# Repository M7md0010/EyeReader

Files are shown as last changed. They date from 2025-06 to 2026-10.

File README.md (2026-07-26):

# EyeReader — Assistive Blink-to-Speech & Smart-Home Wearable

> A wearable eye-blink interface that translates eyelid gestures into spoken phrases and smart-home commands for individuals with paralysis or speech impairments.

**Authors:** Mohamed Sameh & Mohamed Elawady  
**License:** MIT

---

## Table of Contents

- [Project Overview](#project-overview)
- [2022 → 2026 Evolution](#2022--2026-evolution)
- [Hardware Specifications (2026 Remaster)](#hardware-specifications-2026-remaster)
- [Firmware Architecture (2026 Remaster)](#firmware-architecture-2026-remaster)
- [Repository Structure](#repository-structure)
- [Build & Production Files](#build--production-files)
- [Blink Code Reference](#blink-code-reference)
- [Getting Started](#getting-started)
- [License](#license)

---

## Project Overview

EyeReader is a wearable assistive device that decodes voluntary eye-blink patterns — measured via a Time-of-Flight proximity sensor — into a set of pre-programmed actions. In **Speaking Mode**, blink codes trigger audio playback of phrases such as *"I need to drink"* or *"Help!!"* through a DFPlayer Mini. In **Smart-Home Mode**, the same blink vocabulary toggles GPIO-controlled appliances (lights, fans, doors, AC, etc.).

The system comprises two units:

| Unit | Role |
|---|---|
| **Transmitter** | Glasses-mounted sensor module. Detects eyelid proximity, classifies blink duration via hardware interrupts, and transmits events over BLE. |
| **Receiver** | Bedside or wearable hub. Decodes blink sequences, drives audio playback, and controls smart-home relays. |

---

## 2022 → 2026 Evolution

This project was originally built in 2022 as a high-school engineering prototype and has since been remastered as a university-level Computer Engineering portfolio piece.

| Aspect | 2022 Prototype | 2026 Remaster |
|---|---|---|
| **MCU** | 2× ESP32 DevKits (breadboarded) | Nordic nRF52840 SoC on a custom 4-layer HDI PCB |
| **Sensor** | Generic IR reflectance sensor | VL53L0X Time-of-Flight sensor over a flexible printed circuit (FPC) |
| **Wireless** | ESP-NOW (Wi-Fi based, high power) | Bluetooth Low Energy 5.0 (BLE) |
| **Antenna** | External PCB trace (hand-routed) | Standard built-in onboard zig-zag trace antenna (validated RF performance) |
| **Power Management** | USB-only, no battery | MCP73831 single-cell LiPo charger with integrated thermal regulation |
| **Haptic Driver** | Direct GPIO (no protection) | BSS138 N-Channel MOSFET + 1N4148 flyback diode motor driver |
| **Form Factor** | Breadboard + jumper wires (~120 × 80 mm) | 15 × 50 mm 4-layer HDI PCB |
| **Firmware Model** | Blocking `while` loops with `delay()` calls | Event-driven FreeRTOS architecture with hardware interrupts |
| **Power Consumption** | ~80 mA continuous (Wi-Fi always on) | ~8 µA deep sleep (BLE advertising + `waitForEvent()`) |
| **Code** | Monolithic `.ino` sketches | Modular C++ with ISR-driven state machine and RTOS software timers |

> The original 2022 code and Fritzing circuit images are preserved in the [`/Archive_2022`](Archive_2022/) directory for reference.

---

## Hardware Specifications (2026 Remaster)

### PCB

- **Dimensions:** 15 × 50 mm, 4-layer HDI stack-up
- **Fabrication:** Standard JLCPCB/PCBWay-compatible Gerber output
- **Design Tool:** KiCad 8.x

### Core Components

| Component | Part Number | Function |
|---|---|---|
| **SoC** | Nordic nRF52840 | ARM Cortex-M4F @ 64 MHz, BLE 5.0, 1 MB Flash, 256 KB RAM |
| **ToF Sensor** | VL53L0X (ST) | 940 nm VCSEL laser ranging, I²C, hardware interrupt on threshold crossing. Mounted on FPC for flexible glasses-frame routing. |
| **LiPo Charger** | MCP73831 (Microchip) | Single-cell Li-Ion/LiPo charge management, 500 mA programmable charge current, thermal regulation |
| **Haptic Driver** | BSS138 + 1N4148 | Low-side N-FET switch for ERM vibration motor with flyback protection diode |

### RF Design

The RF front-end utilizes the **standard built-in onboard zig-zag trace antenna** pattern routed on the PCB top layer. This antenna geometry is a well-characterized design for 2.4 GHz BLE applications and was selected for its compact footprint and proven radiation efficiency without requiring an external antenna or matching network. The design has been validated for reliable BLE communication at the target operating range.

### Power Architecture

```
USB-C → MCP73831 → LiPo Cell (3.7V)
                 ↘ LDO → nRF52840 (1.8V–3.3V)
                       → VL53L0X (2.8V via XSHUT gating)
```

- **Deep sleep current:** ~8 µA (nRF52840 System ON, RAM retained, BLE advertising at 244 ms interval)
- **Active sensing current:** ~12 mA (ToF continuous ranging at 50 ms period)

---

## Firmware Architecture (2026 Remaster)

The firmware has been completely re-architected from the original ESP32 blocking-loop design to an **event-driven RTOS model** on the nRF52840.

### Key Design Decisions

1. **Hardware Interrupt-Driven Sensing:**  
   The VL53L0X is configured with a programmable distance threshold. When the eyelid crosses this threshold, the sensor asserts its GPIO interrupt pin. An ISR (`tof_isr`) captures the timestamp on both edges — eliminating continuous polling and enabling the MCU to remain in deep sleep between blinks.

2. **FreeRTOS Software Timers for Haptics:**  
   Haptic feedback (vibration motor pulse on long blinks ≥ 1000 ms) is managed by a one-shot FreeRTOS `SoftwareTimer` rather than a blocking `delay()`. This keeps the main loop non-blocking and power-efficient.

3. **Dynamic Threshold Detection:**  
   The blink threshold (currently 20 mm) is designed to be dynamically calibrated via a button ISR (pin reserved, TODO in firmware). This accommodates per-user anatomical variation.

4. **BLE Notification Model:**  
   Blink duration is transmitted as a 32-bit unsigned integer via a BLE GATT characteristic with `NOTIFY` property. The receiver subscribes to notifications and processes blink codes asynchronously — no polling or request/response overhead.

5. **Ultra-Low Power Loop:**  
   After processing a blink event, the main loop calls `waitForEvent()` (ARM WFE instruction), immediately returning the CPU to deep sleep. The loop thread is also suspended at startup via `suspendLoop()`, ensuring zero idle power waste.

### Firmware Files

| File | Description |
|---|---|
| [`Firmware/Transmitter.cpp`](Firmware/Transmitter.cpp) | nRF52840 transmitter — ISR-driven blink detection, BLE GATT server, FreeRTOS haptic timer |
| [`Firmware/EyeReaderReciever.ino`](Firmware/EyeReaderReciever.ino) | ESP32 BLE client receiver — blink code decoder, DFPlayer audio, smart-home GPIO control |

---

## Repository Structure

```
EyeReader/
├── Hardware/              # KiCad 8.x project files (schematic, PCB, netlist)
│   ├── v1.0.kicad_pro
│   ├── v1.0.kicad_sch
│   ├── v1.0.kicad_pcb
│   └── ...
├── Firmware/              # nRF52840 + ESP32 BLE firmware (2026)
│   ├── Transmitter.cpp
│   └── EyeReaderReciever.ino
├── Docs/                  # Generated documentation (schematic PDFs, etc.)
├── Production/            # Manufacturing output (Gerbers, drill files)
├── Archive_2022/          # Original high-school prototype code & images
│   ├── EyeReaderTransmitter_ESP32.ino
│   ├── EyeReaderReciever_ESP32.ino
│   ├── Transmitter Circuit.jpg
│   └── Receiver Circuit.jpg
├── generate_production.sh # KiCad CLI export automation script
└── README.md              # This file
```

---

## Build & Production Files

### Automated Export Script

A bash script is provided to generate all manufacturing and documentation files from the KiCad project:

```bash
./generate_production.sh
```

This script uses the KiCad CLI to:
1. **Export schematic PDF** → `Docs/EyeReader_Schematic.pdf`
2. **Export Gerber files** → `Production/`
3. **Export drill files** → `Production/`

> **Prerequisites:** KiCad 8.x must be installed and `kicad-cli` available on `$PATH`.

---

## Blink Code Reference

Each blink is classified by duration:  
- `0` = Short blink (1–2 s)  
- `1` = Long blink (2–3 s)  
- `2` = End-of-sequence marker (0.5–1 s)  
- **Mode switch** = Very long blink (3–5 s)

### Speaking Mode

| Code | Phrase |
|---|---|
| `0-0-2` | "I need to drink" |
| `0-1-2` | "I need to eat" |
| `1-0-0-2` | "I need to obey nature's call" |
| `1-1-0-2` | "Help!!" |
| `1-0-1-2` | "Hello" |
| `1-1-2` | "I am cold" |
| `1-1-1-2` | "Thanks" |
| `0-1-0-2` | "Give me a hug" |
| `0-0-1-2` | "I need to shower" |
| `0-0-0-2` | "I love you" |
| `0-1-1-2` | "Tell me a joke" |

### Smart-Home Mode

| Code | Action |
|---|---|
| `0-0-2` | Toggle lamp |
| `0-1-2` | Toggle TV |
| `1-0-0-2` | Toggle fan |
| `1-1-0-2` | Open/close curtains |
| `1-0-1-2` | Open/close door |
| `1-1-2` | Toggle AC/heater |
| `1-1-1-2` | Read a book |
| `0-1-0-2` | Medication schedule |
| `0-0-1-2` | Monitor cameras |
| `0-0-0-2` | Make a call |
| `0-1-1-2` | Measure heart rate |

---

## Getting Started

### Hardware
1. Open the KiCad project from `Hardware/v1.0.kicad_pro`.
2. Review the schematic and PCB layout.
3. Run `./generate_production.sh` to generate Gerber and drill files for PCB fabrication.

### Firmware
1. **Transmitter (nRF52840):** Open `Firmware/Transmitter.cpp` in the Arduino IDE with the Adafruit nRF52 BSP installed. Select the `Adafruit Feather nRF52840` board (or your target) and upload.
2. **Receiver (ESP32):** Open `Firmware/EyeReaderReciever.ino` in the Arduino IDE with the ESP32 board package. Upload to the receiver ESP32.

### Dependencies
- [Adafruit nRF52 Arduino BSP](https://github.com/adafruit/Adafruit_nRF52_Arduino)
- [Adafruit VL53L0X Library](https://github.com/adafruit/Adafruit_VL53L0X)
- [DFRobotDFPlayerMini Library](https://github.com/DFRobot/DFRobotDFPlayerMini)

---

## License

This project is licensed under the MIT License — see the [LICENSE](LICENSE) file for details.

---

**Mohamed Sameh** · [GitHub](https://github.com/m7md0010)  
**Mohamed Elawady** · Co-Author

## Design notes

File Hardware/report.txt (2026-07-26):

Info: Processing symbol 'C1:'.
Info: Processing symbol 'L3:'.
Info: Processing symbol 'C2:'.
Info: Processing symbol 'J2:'.
Info: Processing symbol 'C3:'.
Info: Processing symbol 'J3:'.
Info: Processing symbol 'C4:'.
Info: Processing symbol 'J4:'.
Info: Processing symbol 'C5:'.
Info: Processing symbol 'L1:'.
Info: Processing symbol 'C6:'.
Info: Processing symbol 'C12:'.
Info: Processing symbol 'C7:'.
Info: Processing symbol 'L2:'.
Info: Processing symbol 'C8:'.
Info: Processing symbol 'L4:'.
Info: Processing symbol 'C9:'.
Info: Processing symbol 'M1:'.
Info: Processing symbol 'C10:'.
Info: Processing symbol 'Q1:Package_TO_SOT_SMD:SOT-23'.
Info: Processing symbol 'C11:'.
Info: Processing symbol 'R1:'.
Info: Processing symbol 'R2:'.
Info: Processing symbol 'R3:'.
Info: Processing symbol 'C13:'.
Info: Processing symbol 'R4:'.
Info: Processing symbol 'C14:'.
Info: Processing symbol 'R5:'.
Info: Processing symbol 'C15:'.
Info: Processing symbol 'R6:'.
Info: Processing symbol 'C16:'.
Info: Processing symbol 'R7:'.
Info: Processing symbol 'C17:'.
Info: Processing symbol 'R8:'.
Info: Processing symbol 'C18:'.
Info: Processing symbol 'R9:'.
Info: Processing symbol 'C19:'.
Info: Processing symbol 'U1:Package_DFN_QFN:DFN-8-1EP_3x2mm_P0.5mm_EP1.7x1.4mm'.
Info: Processing symbol 'C20:'.
Info: Processing symbol 'U2:Package_DFN_QFN:Nordic_AQFN-73-1EP_7x7mm_P0.5mm'.
Info: Processing symbol 'D1:'.
Info: Processing symbol 'U3:LGA12_STM'.
Info: Processing symbol 'D2:Diode_THT:D_DO-35_SOD27_P7.62mm_Horizontal'.
Info: Processing symbol 'Y1:'.
Info: Processing symbol 'J1:'.
Add D2 (footprint 'Diode_THT:D_DO-35_SOD27_P7.62mm_Horizontal').
Add U2 (footprint 'Package_DFN_QFN:Nordic_AQFN-73-1EP_7x7mm_P0.5mm').
Add Q1 (footprint 'Package_TO_SOT_SMD:SOT-23').
Add U1 (footprint 'Package_DFN_QFN:DFN-8-1EP_3x2mm_P0.5mm_EP1.7x1.4mm').
Add U3 (footprint 'LGA12_STM').
Warning: Warning: U3 footprint 'LGA12_STM' is missing a library name. Use the full 'Library:Footprint' format to avoid repeated update notifications.
Error: Cannot add C7 (no footprint assigned).
Error: Cannot add C8 (no footprint assigned).
Error: Cannot add C9 (no footprint assigned).
Error: Cannot add C10 (no footprint assigned).
Error: Cannot add C11 (no footprint assigned).
Error: Cannot add C6 (no footprint assigned).
Error: Cannot add C12 (no footprint assigned).
Error: Cannot add C13 (no footprint assigned).
Error: Cannot add C14 (no footprint assigned).
Error: Cannot add C15 (no footprint assigned).
Error: Cannot add C16 (no footprint assigned).
Error: Cannot add C17 (no footprint assigned).
Error: Cannot add C18 (no footprint assigned).
Error: Cannot add C19 (no footprint assigned).
Error: Cannot add C20 (no footprint assigned).
Error: Cannot add D1 (no footprint assigned).
Error: Cannot add R2 (no footprint assigned).
Error: Cannot add J1 (no footprint assigned).
Error: Cannot add R3 (no footprint assigned).
Error: Cannot add L3 (no footprint assigned).
Error: Cannot add R4 (no footprint assigned).
Error: Cannot add J4 (no footprint assigned).
Error: Cannot add R5 (no footprint assigned).
Error: Cannot add L4 (no footprint assigned).
Error: Cannot add R6 (no footprint assigned).
Error: Cannot add J3 (no footprint assigned).
Error: Cannot add R7 (no footprint assigned).
Error: Cannot add M1 (no footprint assigned).
Error: Cannot add R8 (no footprint assigned).
Error: Cannot add C1 (no footprint assigned).
Error: Cannot add R9 (no footprint assigned).
Error: Cannot add C2 (no footprint assigned).
Error: Cannot add C3 (no footprint assigned).
Error: Cannot add J2 (no footprint assigned).
Error: Cannot add L1 (no footprint assigned).
Error: Cannot add R1 (no footprint assigned).
Error: Cannot add C4 (no footprint assigned).
Error: Cannot add C5 (no footprint assigned).
Error: Cannot add L2 (no footprint assigned).
Error: Cannot add Y1 (no footprint assigned).

Info: Total warnings: 1, errors: 40.

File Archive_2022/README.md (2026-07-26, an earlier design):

# Archive — 2022 High School Prototype

This directory contains the original EyeReader code and circuit images from the 2022 prototype.

These files are preserved for historical reference. The 2022 version used:
- 2× ESP32 DevKit boards communicating via **ESP-NOW**
- Generic IR reflectance sensor for blink detection
- Blocking `while` loops with `delay()` calls
- Breadboard construction with jumper wires

## Files

| File | Description |
|---|---|
| `EyeReaderTransmitter_ESP32.ino` | Original ESP32 transmitter sketch (IR sensor + ESP-NOW) |
| `EyeReaderReciever_ESP32.ino` | Original ESP32 receiver sketch (ESP-NOW + DFPlayer) |
| `Transmitter Circuit.jpg` | Fritzing-style wiring diagram for the transmitter |
| `Receiver Circuit.jpg` | Fritzing-style wiring diagram for the receiver |

> See the root [README.md](../README.md) for a detailed comparison with the 2026 remaster.

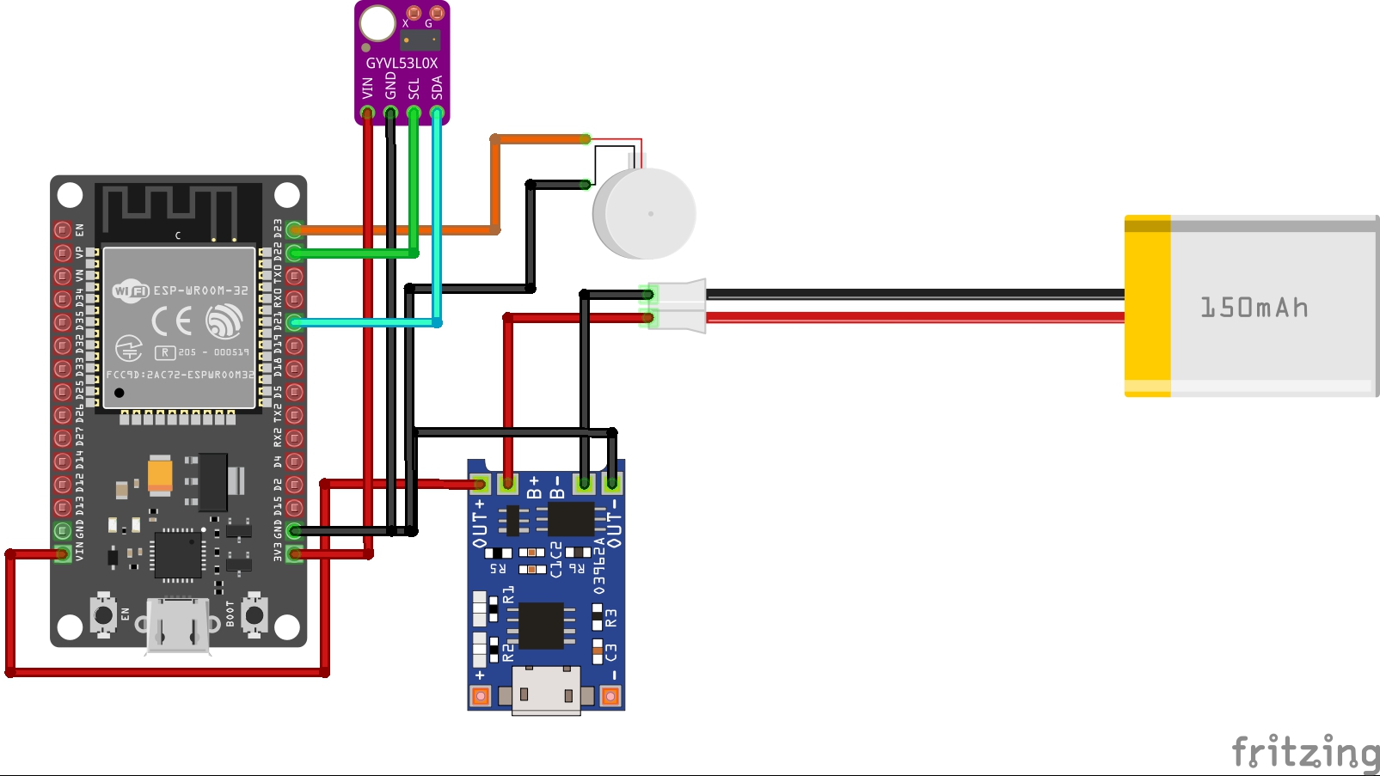
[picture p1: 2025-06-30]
Transmitter Circuit.jpg

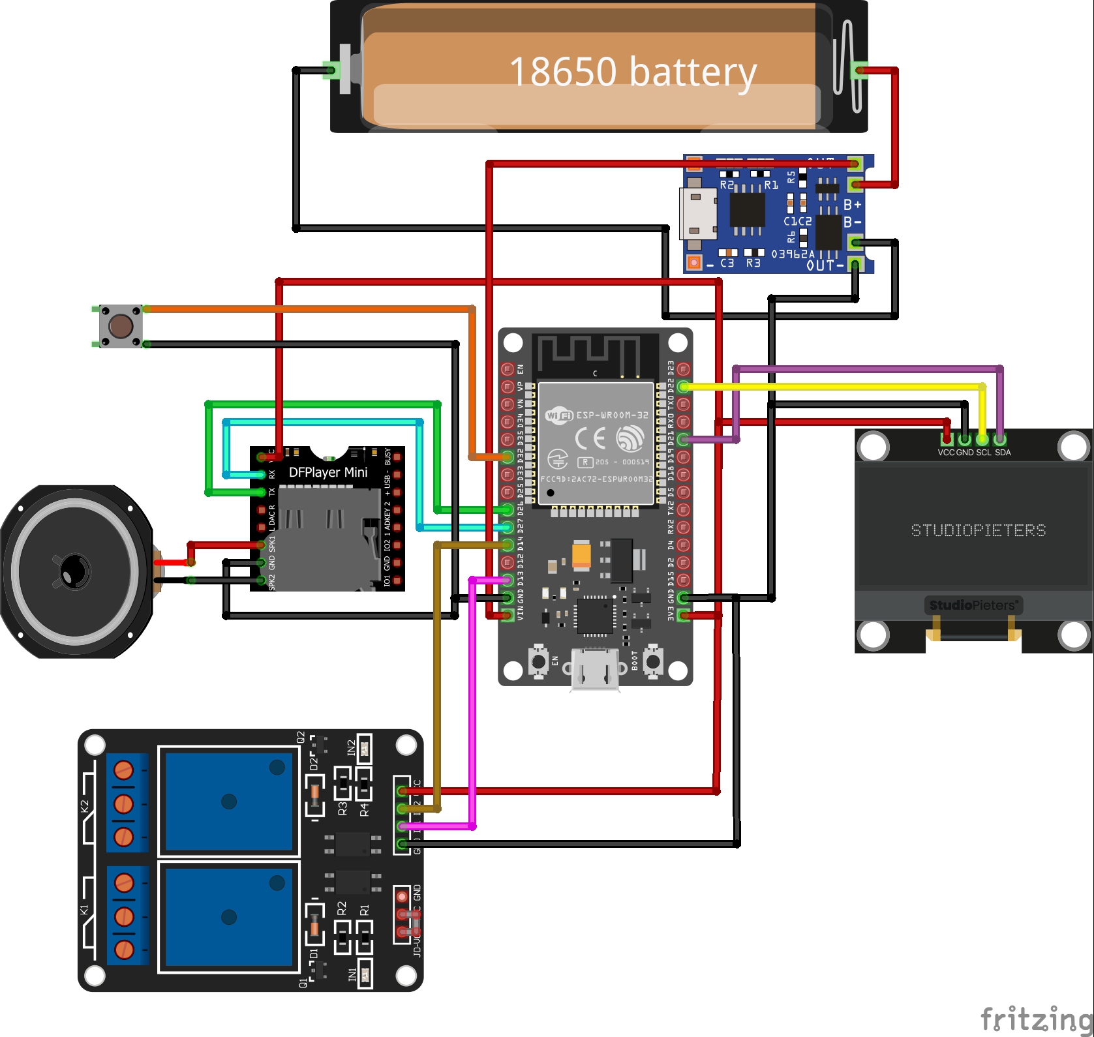
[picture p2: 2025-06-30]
Receiver Circuit.jpg

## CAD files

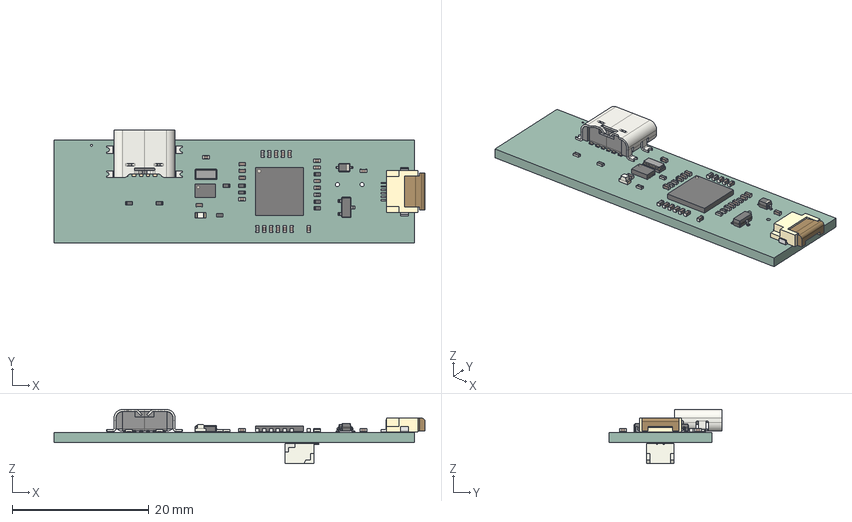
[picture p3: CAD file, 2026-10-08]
Hardware/EyeReader_3D.step
54.2 x 16.5 x 7.90 mm
C_0402_1005Metric x 20
Crystal_SMD_3215-2Pin_3.2x1.5mm
D_SOD-323
R_0402_1005Metric x 9
L_0402_1005Metric x 4
USB_C_Receptacle_6P_TopMnt_Horizontal_GCT_USB4135-GF-A
LED_0603_1608Metric
Nordic_AQFN-73-1EP_7x7mm_P0.5mm
SOT-23
lock
pins
Maxim_WSON-8-1EP_3x2mm_P0.5mm_EP1.75x1.63mm
JST_SH_SM02B-SRSS-TB_1x02-1MP_P1.00mm_Horizontal
v1.0_PCB

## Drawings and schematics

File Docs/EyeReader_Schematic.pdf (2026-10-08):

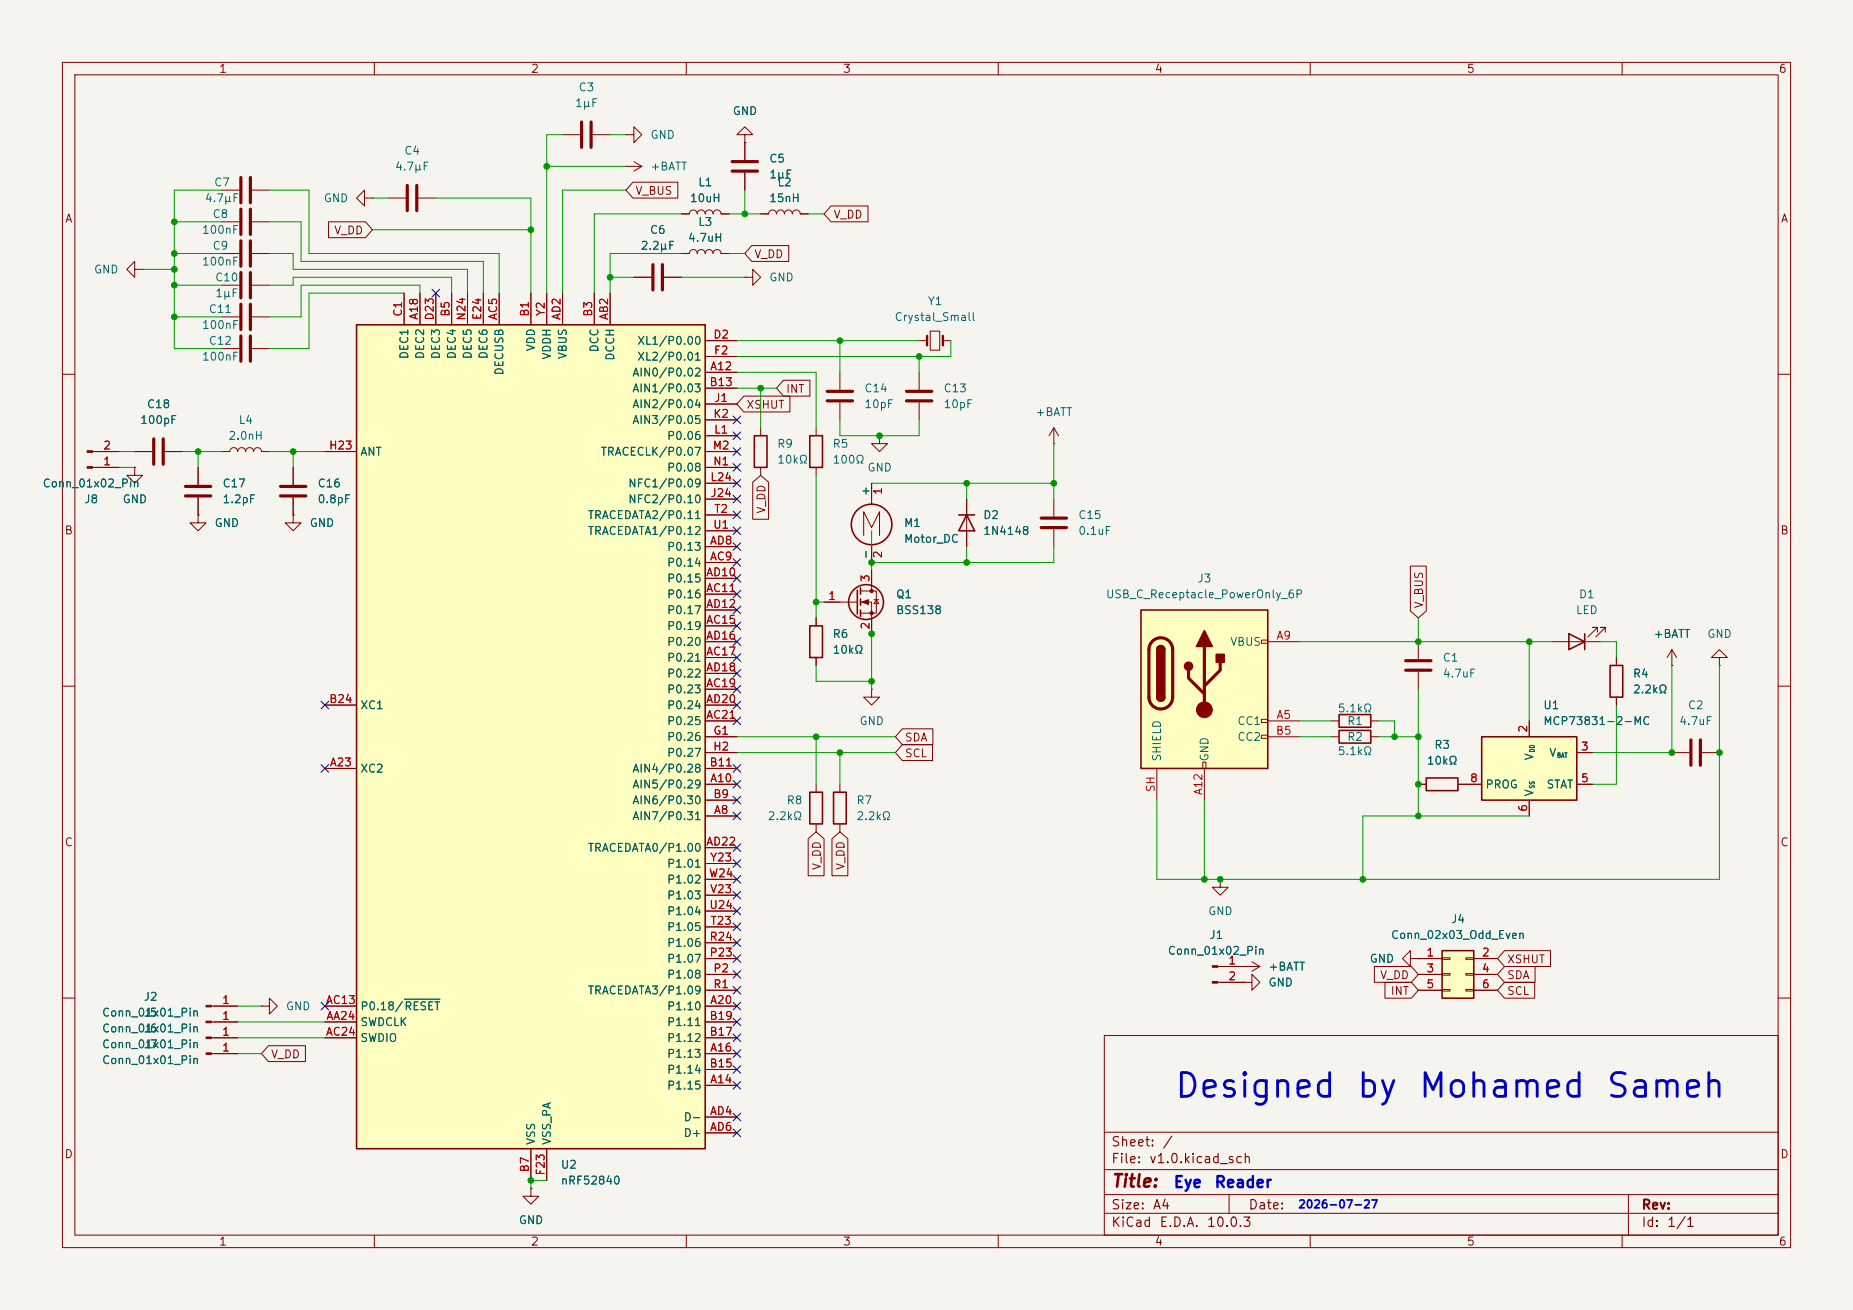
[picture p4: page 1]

Size: A4 | Rev:
KiCad E.D.A. 10.0.3 | Id: 1/1

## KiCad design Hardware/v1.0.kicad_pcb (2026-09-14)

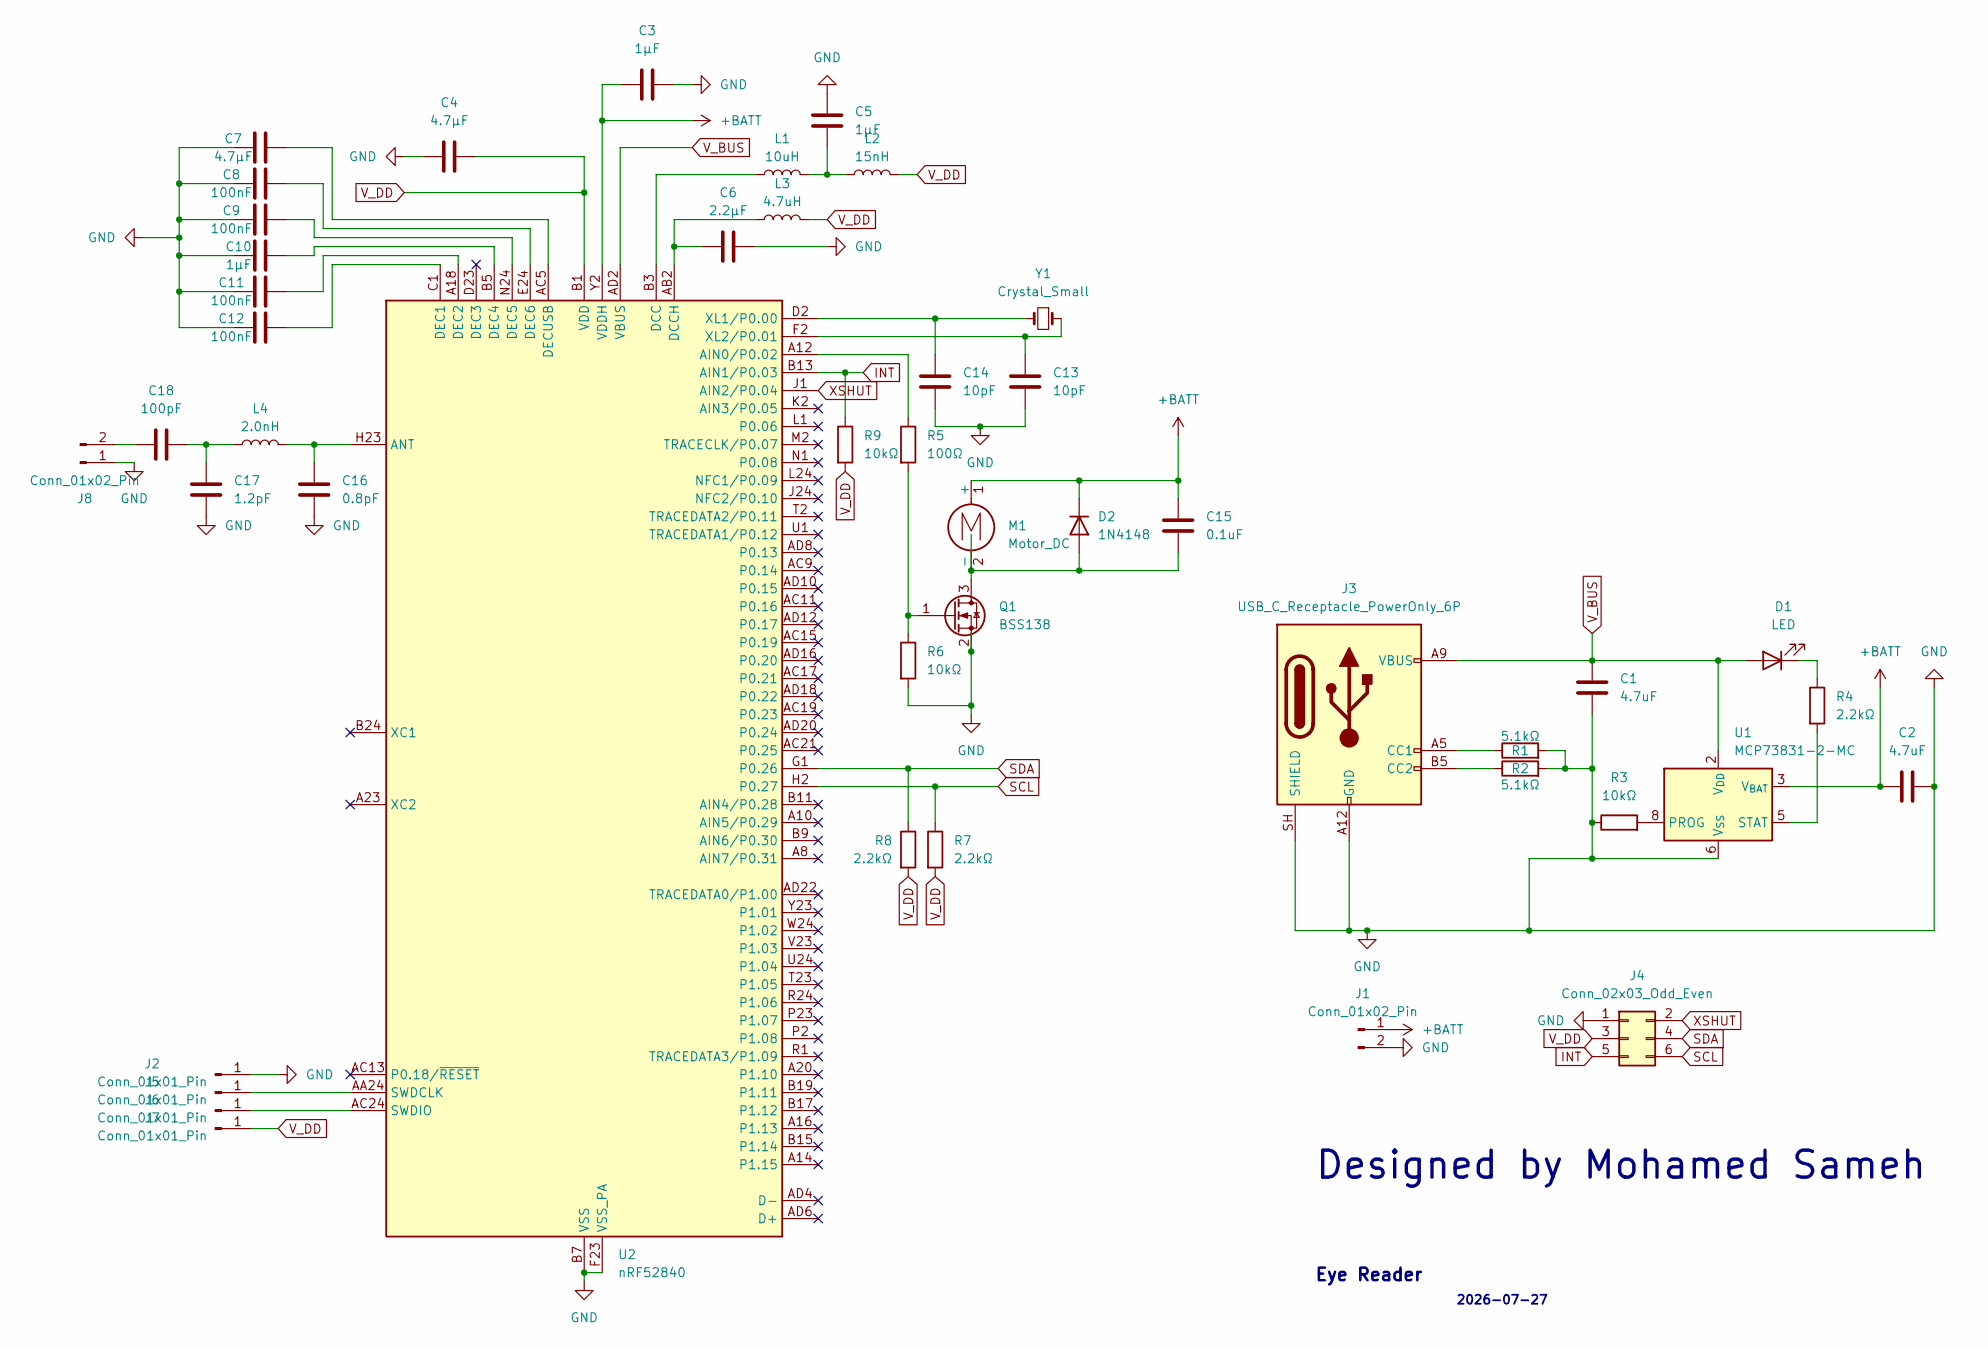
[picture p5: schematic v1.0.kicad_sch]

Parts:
C1, C2: 4.7uF; C_0402_1005Metric
C3, C5, C10: 1μF; C_0402_1005Metric
C4, C7: 4.7μF; C_0402_1005Metric
C6: 2.2μF; C_0402_1005Metric
C8, C9, C11, C12: 100nF; C_0402_1005Metric
C13, C14: 10pF; C_0402_1005Metric
C15: 0.1uF; C_0402_1005Metric
C16: 0.8pF; C_0402_1005Metric
C17: 1.2pF; C_0402_1005Metric
C18: 100pF; C_0402_1005Metric
D1: LED; LED_0603_1608Metric
D2: 1N4148; D_SOD-323
J1: Conn_01x02_Pin; JST_SH_SM02B-SRSS-TB_1x02-1MP_P1.00mm_Horizontal
J2, J5, J6, J7: Conn_01x01_Pin; TestPoint_Pad_D1.0mm
J3: USB_C_Receptacle_PowerOnly_6P; USB_C_Receptacle_GCT_USB4135-GF-A_6P_TopMnt_Horizontal
J4: Conn_02x03_Odd_Even; Hirose_FH12-6S-0.5SH_1x06-1MP_P0.50mm_Horizontal
J8: Conn_01x02_Pin; Texas_SWRA117D_2.4GHz_Left
L1: 10uH; L_0402_1005Metric
L2: 15nH; L_0402_1005Metric
L3: 4.7uH; L_0402_1005Metric
L4: 2.0nH; L_0402_1005Metric
M1: Motor_DC; SolderWire-0.1sqmm_1x02_P3.6mm_D0.4mm_OD1mm
Q1: BSS138; SOT-23
R1, R2: 5.1kΩ; R_0402_1005Metric
R3, R6, R9: 10kΩ; R_0402_1005Metric
R4, R7, R8: 2.2kΩ; R_0402_1005Metric
R5: 100Ω; R_0402_1005Metric
U1: MCP73831-2-MC; DFN-8-1EP_3x2mm_P0.5mm_EP1.7x1.4mm
U2: nRF52840; Nordic_AQFN-73-1EP_7x7mm_P0.5mm
Y1: Crystal_Small; Crystal_SMD_3215-2Pin_3.2x1.5mm

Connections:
+BATT: C2.1, C3.2, C15.2, D2.1 (K), J1.1, M1.1 (+), U1.3 (V_{BAT}), U1.4 (V_{BAT}), U2.Y2 (VDDH)
GND: C1.2, C2.2, C3.1, C4.1, C5.2, C6.2, C7.2, C8.2, C9.2, C10.2, C11.2, C12.2, C13.1, C14.1, C16.1, C17.1, J1.2, J2.1 (Pin_1_1), J3.A12 (GND), J3.B12 (GND), J3.SH (SHIELD), J4.1, J8.1, Q1.2 (S), R1.2, R2.2, R3.1, R6.2, U1.6 (V_{SS}), U2.B7 (VSS), U2.EP (VSS), U2.F23 (VSS_PA); also elsewhere on the board
INT: J4.5, R9.1, U2.B13 (AIN1/P0.03)
unnamed: C5.1, L1.2, L2.1
unnamed: C17.2, C18.2, L4.1
unnamed: D1.1 (K), R4.1
unnamed: C15.1, D2.2 (A), M1.2 (-), Q1.3 (D)
unnamed: J3.A5 (CC1), R1.1
unnamed: J3.B5 (CC2), R2.1
unnamed: J5.1 (Pin_1_1), U2.AA24 (SWDCLK)
unnamed: J6.1 (Pin_1_1), U2.AC24 (SWDIO)
unnamed: C18.1, J8.2
unnamed: Q1.1 (G), R5.2, R6.1
unnamed: R3.2, U1.8 (PROG)
unnamed: R4.2, U1.5 (STAT)
unnamed: R5.1, U2.A12 (AIN0/P0.02)
unnamed: C16.2, L4.2, U2.H23 (ANT)
unnamed: L1.1, U2.B3 (DCC)
unnamed: C6.1, L3.1, U2.AB2 (DCCH)
unnamed: C12.1, U2.C1 (DEC1)
unnamed: C11.1, U2.A18 (DEC2)
unnamed: C10.1, U2.B5 (DEC4)
unnamed: C9.1, U2.N24 (DEC5)
unnamed: C8.1, U2.E24 (DEC6)
unnamed: C7.1, U2.AC5 (DECUSB)
unnamed: C14.2, U2.D2 (XL1/P0.00), Y1.2
unnamed: C13.2, U2.F2 (XL2/P0.01), Y1.1
SCL: J4.6, R7.1, U2.H2 (P0.27)
SDA: J4.4, R8.1, U2.G1 (P0.26)
V_BUS: C1.1, D1.2 (A), J3.A9 (VBUS), J3.B9 (VBUS), U1.1 (V_{DD}), U1.2 (V_{DD}), U2.AD2 (VBUS)
V_DD: C4.2, J4.3, J7.1 (Pin_1_1), L2.2, L3.2, R7.2, R8.2, R9.2, U2.A22 (VDD), U2.AD14 (VDD), U2.AD23 (VDD), U2.B1 (VDD), U2.W1 (VDD); also elsewhere on the board
XSHUT: J4.2, U2.J1 (AIN2/P0.04)

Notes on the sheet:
Designed by Mohamed Sameh
2026-07-27
Eye Reader

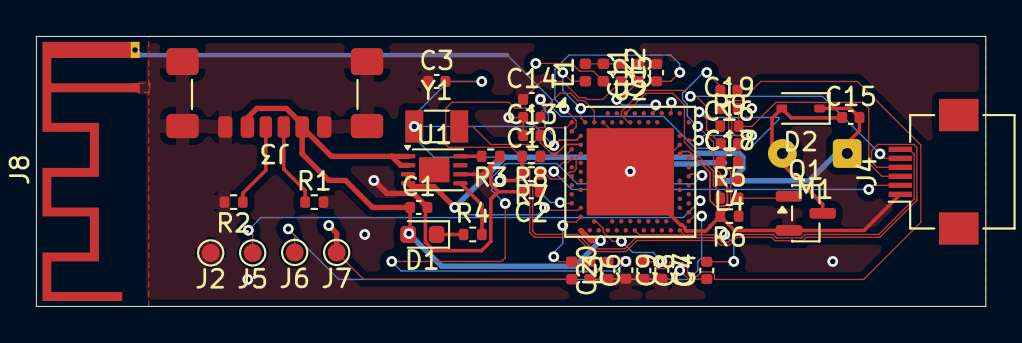
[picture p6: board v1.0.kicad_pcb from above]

Board: 4 copper layers, 52.7 x 15.0 mm, 48 parts (1 on the bottom side), 32 nets.

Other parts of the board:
C19: 4.7uF; C_0402_1005Metric
C20: 100nF; C_0402_1005Metric

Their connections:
GND: C19.1, C20.1; also elsewhere on the board
V_DD: C19.2, C20.2; also elsewhere on the board

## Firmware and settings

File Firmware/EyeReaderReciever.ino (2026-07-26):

#include <BLEDevice.h>
#include <BLEUtils.h>
#include <BLEScan.h>
#include <BLEAdvertisedDevice.h>
#include "DFRobotDFPlayerMini.h"

// --- BLE UUIDs (Must match the Transmitter) ---
static BLEUUID serviceUUID((uint16_t)0x180A);
static BLEUUID charUUID((uint16_t)0x2A57);

static boolean doConnect = false;
static boolean connected = false;
static boolean doScan = false;
static BLERemoteCharacteristic* pRemoteCharacteristic;
static BLEAdvertisedDevice* myDevice;

// --- Hardware & State Variables ---
DFRobotDFPlayerMini myDFPlayer;
const int lightME = 2;

char n[4] = {'0', '0', '0', '0'};
int u = 0;
bool SpeakingModeOn = true;
String Sentence = "Nothing Yet";

// --- Original Logic Execution ---
void On_OFF(int pin) {
  digitalWrite(pin, digitalRead(pin) == HIGH ? LOW : HIGH);
}

void processBlink(uint32_t duration) {
  // Briefly flash the onboard LED to indicate a received blink
  digitalWrite(lightME, HIGH);
  delay(50);
  digitalWrite(lightME, LOW);

  bool TheCodeEnded = false;
  Serial.println(duration);
  
  if (500 < duration && duration < 1000) {
    Serial.println((String) "the index " + u + " was assigned to 2\n");
    n[u] = '2';
    TheCodeEnded = true;
    u = 0;
  }
  else if (1000 < duration && duration < 2000) {
    if (u < 4) {
      Serial.println((String) "the index " + u + " was assigned to 0\n");
      n[u] = '0';
      u++;
    }
  }
  else if (2000 < duration && duration < 3000) {
    if (u < 4) {
      Serial.println((String) "the index " + u + " was assigned to 1\n");
      n[u] = '1';
      u++;
    }
  }
  else if (3000 < duration && duration < 5000) {
    if (SpeakingModeOn == true) {
      SpeakingModeOn = false;
      Serial.print("Switched to SmartHome Mode\n");
    } else {
      SpeakingModeOn = true;
      Serial.print("Switched to Speaking Mode\n");
    }
  }

  if (TheCodeEnded == true) {
    for (int i = 0; i < 4; i++) {
      Serial.println(n[i]);
    }
  }

  if (SpeakingModeOn) {
    if (n[0] == '0' && n[1] == '0' && n[2] == '2') {
      Sentence = "I need to drink";
      Serial.println(Sentence);
      myDFPlayer.play(1);
    } else if (n[0] == '0' && n[1] == '1' && n[2] == '2') {
      Sentence = "I need to Eat";
      Serial.println(Sentence);
      myDFPlayer.play(2);
    } else if (n[0] == '1' && n[1] == '0' && n[2] == '0' && n[3] == '2') {
      Sentence = "I need to obey nature's call";
      Serial.println(Sentence);
      myDFPlayer.play(3);
    } else if (n[0] == '1' && n[1] == '1' && n[2] == '0' && n[3] == '2') {
      Sentence = "Help!!";
      Serial.println(Sentence);
      myDFPlayer.play(4);
    } else if (n[0] == '1' && n[1] == '0' && n[2] == '1' && n[3] == '2') {
      Sentence = "Hello";
      Serial.println(Sentence);
      myDFPlayer.play(5);
    } else if (n[0] == '1' && n[1] == '1' && n[2] == '2') {
      Sentence = "I am Cold";
      Serial.println(Sentence);
      myDFPlayer.play(6);
    } else if (n[0] == '1' && n[1] == '1' && n[2] == '1' && n[3] == '2') {
      Sentence = "Thanks";
      Serial.println(Sentence);
      myDFPlayer.play(7);
    } else if (n[0] == '0' && n[1] == '1' && n[2] == '0' && n[3] == '2') {
      Sentence = "Give me a hug";
      Serial.println(Sentence);
      myDFPlayer.play(8);
    } else if (n[0] == '0' && n[1] == '0' && n[2] == '1' && n[3] == '2') {
      Sentence = "I need to shower";
      Serial.println(Sentence);
      myDFPlayer.play(9);
    } else if (n[0] == '0' && n[1] == '0' && n[2] == '0' && n[3] == '2') {
      Sentence = "I love you";
      Serial.println(Sentence);
      myDFPlayer.play(10);
    } else if (n[0] == '0' && n[1] == '1' && n[2] == '1' && n[3] == '2') {
      Sentence = "Tell me a joke";
      Serial.println(Sentence);
      myDFPlayer.play(11);
    }
  } else {
    if (n[0] == '0' && n[1] == '0' && n[2] == '2') {
      Sentence = "Turn on/off the lamp";
      Serial.println(Sentence);
      On_OFF(23);
    } else if (n[0] == '0' && n[1] == '1' && n[2] == '2') {
      Sentence = "Turn on/off the TV";
      Serial.println(Sentence);
      On_OFF(33);
    } else if (n[0] == '1' && n[1] == '0' && n[2] == '0' && n[3] == '2') {
      Sentence = "Turn on/off the Fan";
      Serial.println(Sentence);
      On_OFF(25);
    } else if (n[0] == '1' && n[1] == '1' && n[2] == '0' && n[3] == '2') {
      Sentence = "Close/Open the Curtains";
      Serial.println(Sentence);
      On_OFF(26);
    } else if (n[0] == '1' && n[1] == '0' && n[2] == '1' && n[3] == '2') {
      Sentence = "Open/Close Door";
      Serial.println(Sentence);
      On_OFF(27);
    } else if (n[0] == '1' && n[1] == '1' && n[2] == '2') {
      Sentence = "AC/Heater on/off";
      Serial.println(Sentence);
      On_OFF(13);
    } else if (n[0] == '1' && n[1] == '1' && n[2] == '1' && n[3] == '2') {
      Sentence = "Read a book";
      Serial.println(Sentence);
      On_OFF(18);
    } else if (n[0] == '0' && n[1] == '1' && n[2] == '0' && n[3] == '2') {
      Sentence = "Medication schedules";
      Serial.println(Sentence);
      On_OFF(19);
    } else if (n[0] == '0' && n[1] == '0' && n[2] == '1' && n[3] == '2') {
      Sentence = "Monitor Cameras";
      Serial.println(Sentence);
      On_OFF(21);
    } else if (n[0] == '0' && n[1] == '0' && n[2] == '0' && n[3] == '2') {
      Sentence = "Make a call";
      Serial.println(Sentence);
      On_OFF(22);
    } else if (n[0] == '0' && n[1] == '1' && n[2] == '1' && n[3] == '2') {
      Sentence = "Measure Heart Rate";
      Serial.println(Sentence);
      On_OFF(32);
    }
  }

  if (TheCodeEnded == true) {
    for (int k = 0; k < 4; k++) {
      n[k] = '0';
    }
  }
}

// --- BLE Callbacks ---
static void notifyCallback(
  BLERemoteCharacteristic* pBLERemoteCharacteristic,
  uint8_t* pData,
  size_t length,
  bool isNotify) {
    
    if (length >= 4) {
      uint32_t duration;
      memcpy(&duration, pData, sizeof(duration)); // Convert bytes back to 32-bit int
      processBlink(duration);
    }
}

class MyClientCallback : public BLEClientCallbacks {
  void onConnect(BLEClient* pclient) { }
  void onDisconnect(BLEClient* pclient) {
    connected = false;
    Serial.println("Disconnected from Transmitter");
  }
};

bool connectToServer() {
  Serial.print("Forming a connection to ");
  Serial.println(myDevice->getAddress().toString().c_str());
  
  BLEClient*  pClient  = BLEDevice::createClient();
  pClient->setClientCallbacks(new MyClientCallback());
  pClient->connect(myDevice);

  BLERemoteService* pRemoteService = pClient->getService(serviceUUID);
  if (pRemoteService == nullptr) {
    Serial.print("Failed to find our service UUID: ");
    pClient->disconnect();
    return false;
  }

  pRemoteCharacteristic = pRemoteService->getCharacteristic(charUUID);
  if (pRemoteCharacteristic == nullptr) {
    Serial.print("Failed to find our characteristic UUID: ");
    pClient->disconnect();
    return false;
  }

  if(pRemoteCharacteristic->canNotify()) {
    pRemoteCharacteristic->registerForNotify(notifyCallback);
    Serial.println("Successfully subscribed to blink notifications!");
  }

  connected = true;
  return true;
}

class MyAdvertisedDeviceCallbacks: public BLEAdvertisedDeviceCallbacks {
  void onResult(BLEAdvertisedDevice advertisedDevice) {
    if (advertisedDevice.haveServiceUUID() && advertisedDevice.isAdvertisingService(serviceUUID)) {
      BLEDevice::getScan()->stop();
      myDevice = new BLEAdvertisedDevice(advertisedDevice);
      doConnect = true;
      doScan = true;
    }
  }
};

// --- Main Setup & Loop ---
void setup() {
  Serial.begin(115200);
  pinMode(lightME, OUTPUT);
  digitalWrite(lightME, LOW);

  // Init DFPlayer (Using same pins as old code)[cite: 4]
  Serial2.begin(9600, SERIAL_8N1, 23, 22);
  Serial.println(F("\nInitializing DFPlayer ... (May take 3~5 seconds)"));

  if (!myDFPlayer.begin(Serial2, true, true)) {
    Serial.println(F("Unable to begin: Check connection/SD card."));
  } else {
    Serial.println(F("DFPlayer Mini online."));
    myDFPlayer.volume(30);
  }

  // Init BLE Scanner
  Serial.println("Starting BLE Client...");
  BLEDevice::init("");
  BLEScan* pBLEScan = BLEDevice::getScan();
  pBLEScan->setAdvertisedDeviceCallbacks(new MyAdvertisedDeviceCallbacks());
  pBLEScan->setInterval(1349);
  pBLEScan->setWindow(449);
  pBLEScan->setActiveScan(true);
  pBLEScan->start(5, false);
}

void loop() {
  if (doConnect == true) {
    if (connectToServer()) {
      Serial.println("We are now connected to the nRF52840 Transmitter.");
    } else {
      Serial.println("Failed to connect.");
    }
    doConnect = false;
  }

  if (!connected) {
    BLEDevice::getScan()->start(5, false); // Keep scanning if disconnected
    delay(1000);
  }
}

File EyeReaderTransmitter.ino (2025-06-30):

#include <esp_now.h>
#include <WiFi.h>
#include "Adafruit_VL53L0X.h"

const int IRSensor = 15;
const int VibrationMotor = 21;

uint8_t broadcastAddress[] = { 0xE8, 0x6B, 0xEA, 0xC2, 0xE5, 0x04 };

struct __attribute__((packed)) dataPacket {
  int Duration;
  int TOF_Reading;
};

esp_now_peer_info_t peerInfo;

void OnDataSent(const uint8_t *mac_addr, esp_now_send_status_t status) {
  Serial.print("\r\nLast Packet Send Status:\t");
  Serial.println(status == ESP_NOW_SEND_SUCCESS ? "Delivery Success" : "Delivery Fail");
}

void setup() {
  Serial.begin(115200);

  while (! Serial) {
    delay(1);
  }

  pinMode(IRSensor, INPUT);
  pinMode(VibrationMotor, OUTPUT);

  WiFi.mode(WIFI_STA);

  if (esp_now_init() != ESP_OK) {
    Serial.println("Error initializing ESP-NOW");
    return;
  }

  esp_now_register_send_cb(OnDataSent);

  memcpy(peerInfo.peer_addr, broadcastAddress, 6);
  peerInfo.channel = 0;
  peerInfo.encrypt = false;

  if (esp_now_add_peer(&peerInfo) != ESP_OK) {
    Serial.println("Failed to add peer");
    return;
  }
}

void loop() {
  unsigned long startMillis = 0;
  unsigned long endMillis = 0;
  int duration = 0;

  digitalWrite(VibrationMotor, LOW);

  // Wait until the sensor goes LOW
  while (digitalRead(IRSensor) == HIGH) {
    delay(1);
    eyeCloseStatus = Eye_Close(); // Re-check status
  }

  // Start counting time
  startMillis = millis();

  // Wait until the sensor goes HIGH again
  while (digitalRead(IRSensor) == LOW) {
    duration = millis() - startMillis;
    if (duration % 200 == 0) {
      Serial.println(duration);
    }
    if (duration % 1000 == 0 && duration != 0) {
      digitalWrite(VibrationMotor, HIGH);
      delay(100);
      digitalWrite(VibrationMotor, LOW);
    }
  }

  // Stop counting time
  endMillis = millis();

  // Calculate the duration the sensor was LOW
  duration = endMillis - startMillis;

  // Send the duration via ESP-NOW
  dataPacket packet;
  packet.Duration = duration;
  packet.IR_Reading = Eye_D(); // Send the actual distance
  esp_now_send(broadcastAddress, (uint8_t *)&packet, sizeof(packet));

  // Debugging: print the duration to Serial Monitor
  Serial.println(packet.Duration);
}

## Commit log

2025-06-30 Rename Reciver v6.0.jpg to Receiver Circuit.jpg
2025-06-30 Rename Transmitter v6.0.jpg to Transmitter Circuit.jpg
2026-07-26 chore: architect 2026 repo structure, write CE-grade README, and generate KiCad production files
    [v1.0-B_Courtyard.gbr, v1.0-B_Cu.gbl, v1.0-B_Fab.gbr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]
2026-07-26 feat: export 3D STEP model for mechanical integration
    [EyeReader_3D.step]
2026-07-26 docs: add Interactive HTML BOM for hardware assembly
2026-09-14 Re-export all production files via KiCad 10 CLI
    - KiCad source: updated PCB, schematic, project files
    - Gerbers: switched from Protel to KiCad (.gbr) extensions
    - Drill files: regenerated with gerber drill map
    - STEP & GLB: re-exported 3D models
    - Schematic PDF: re-exported
    - Netlist: re-exported (kicad + XML)
    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
    [EyeReader_3D.step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]
2026-10-08 Re-export all production files via KiCad 10 CLI
    [EyeReader_3D.step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]
